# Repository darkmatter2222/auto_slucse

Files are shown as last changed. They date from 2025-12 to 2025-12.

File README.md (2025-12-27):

# Auto SLUCSE - Stepper Motor Controller

A smooth, precision stepper motor controller using **NodeMCU v2 (ESP8266)** with an **A4988 driver** and **SSD1306 OLED display**.





## ✨ Features

- **Constant-speed motion** (no ease-in/out)
- **Selectable speed: 1–8 revolutions per second (RPS)**
- **Momentary button** cycles speed 1 → 2 → 3 → … → 8 → 1 …
- **Simple OLED display** showing current RPS
- **No display updates during motion** - prevents motor jitter
- **ESP8266 watchdog-safe stepping** - periodic `yield()` during motion (no I2C)
- **12V single power supply** option (NodeMCU can run from 12V via VIN)

## 🎬 Demo

On boot, the motor runs continuously (clockwise) at **3 RPS**.

Press the button to cycle speed:
`1 → 2 → 3 → 4 → 5 → 6 → 7 → 8 → 1 → ...`

## 🔧 Hardware Required

| Component | Description |
|---|---|
| NodeMCU v2 | ESP8266-based microcontroller |
| A4988 | Stepper motor driver (or compatible) |
| NEMA 17 | Stepper motor (200 steps/rev, 1.8°) |
| SSD1306 | 128x64 OLED display (I2C, 0x3C address) |
| 12V PSU | Power supply (2A+ recommended) |

## 📌 Pin Configuration

| NodeMCU Pin | GPIO | Connected To |
|---|---|---|
| D5 | GPIO14 | A4988 STEP |
| D6 | GPIO12 | A4988 DIR |
| D1 | GPIO5 | SSD1306 SCL |
| D2 | GPIO4 | SSD1306 SDA |
| D7 | GPIO13 | Speed button (momentary to GND) |
| VIN | - | 12V Power (or 5V) |
| GND | - | Common Ground |

## 📐 Wiring

See **[WIRING.md](WIRING.md)** for complete wiring diagrams.

### Quick Reference
```
┌─────────────┐         ┌─────────────┐         ┌─────────────┐
│   12V PSU   │         │   NodeMCU   │         │    A4988    │
├─────────────┤         ├─────────────┤         ├─────────────┤
│ +12V ───────┼────┬────┼─► VIN       │         │             │
│             │    │    │             │         │             │
│             │    └────┼─────────────┼────────►│ VMOT        │
│             │         │             │         │             │
│ GND ────────┼────┬────┼─► GND       │         │             │
│             │    └────┼─────────────┼────────►│ GND         │
└─────────────┘         │             │         │             │
                        │ D5 (GPIO14) ┼────────►│ STEP        │
                        │ D6 (GPIO12) ┼────────►│ DIR         │
                        │ 3.3V ───────┼────────►│ VDD         │
                        │             │         │             │
                        │ D1 (SCL) ───┼──┐      │ RST ──┬── SLP│
                        │ D2 (SDA) ───┼──┤      │       └─► 3.3V│
                        └─────────────┘  │      └─────────────┘
                                         │
                        ┌─────────────┐  │
                        │   SSD1306   │  │
                        ├─────────────┤  │
                        │ SCL ◄───────┼──┤
                        │ SDA ◄───────┼──┘
                        │ VCC ◄─ 3.3V │
                        │ GND ◄─ GND  │
                        └─────────────┘
```

## 🚀 Build & Upload

### Prerequisites
- [PlatformIO](https://platformio.org/) (VS Code extension recommended)

### Commands
```powershell
# Build
pio run

# Upload to NodeMCU
pio run -t upload

# Monitor serial output
pio device monitor -b 115200
```

## ⚙️ Configuration

Edit `src/main.cpp` to customize:

```cpp
const int STEPS_PER_REV = 200;      // Motor steps per revolution
// Speed is selected at runtime via the button (1-8 RPS).
// Button uses INPUT_PULLUP: wire momentary switch between D7 and GND.
```

## 🔬 Technical Details

### Display Updates
The display **ONLY updates before and after motion** - never during stepping. This is critical because I2C communication during stepping causes motor jitter.

### ESP8266 Watchdog (Important)
On ESP8266, long tight stepping loops can trigger watchdog resets if the background tasks aren’t serviced. The firmware includes a lightweight periodic `yield()` during stepping.

This `yield()`:
- Helps prevent resets that can *look like* “it never reverses” (because the program restarts and re-enters the first phase)
- Does **not** touch I2C/OLED, so it’s far less disruptive than display updates

### Smoothness / Resonance
Some step rates can be audibly harsher because stepper + mechanics can resonate at certain step frequencies.
This firmware keeps step timing strictly periodic for stable torque (no intentional per-step jitter), and relies on driver tuning (current limit, decay behavior) and mechanical setup for best acoustics.

## 📁 Project Structure

```
auto_slucse/
├── src/
│   └── main.cpp          # Main application code
├── test_CFD/              # CFD experiments (STL + notebooks)
│   └── fluid_app/         # Local 3D viewer + GPU LBM prototype
├── platformio.ini        # PlatformIO configuration
├── README.md             # This file
├── WIRING.md             # Detailed wiring guide
└── .gitignore            # Git ignore rules
```

## 🌊 CFD Prototype (Local App)

There is an experimental local app in [test_CFD/fluid_app/README.md](test_CFD/fluid_app/README.md) that:
- Loads the STL in a 3D view (rotate/pivot)
- Lets you select gravity direction and click a water source point
- Runs a GPU-accelerated (PyTorch/CUDA) LBM-style simulation and plays back particle animation

## 🐛 Troubleshooting

| Problem | Solution |
|---|---|
| Motor vibrates but doesn't rotate | Check coil wiring - swap one coil pair |
| Motor doesn't move at all | Verify common ground between PSU and NodeMCU |
| Display not found | Check I2C address (usually 0x3C or 0x3D) |
| Jerky motion | Ensure display updates are between rotations |
| Motor skips steps | Increase minimum delay or reduce speed |

## 📄 License

MIT License - feel free to use and modify!

## 🙏 Acknowledgments

- Adafruit for the excellent GFX and SSD1306 libraries
- The PlatformIO team for the build system

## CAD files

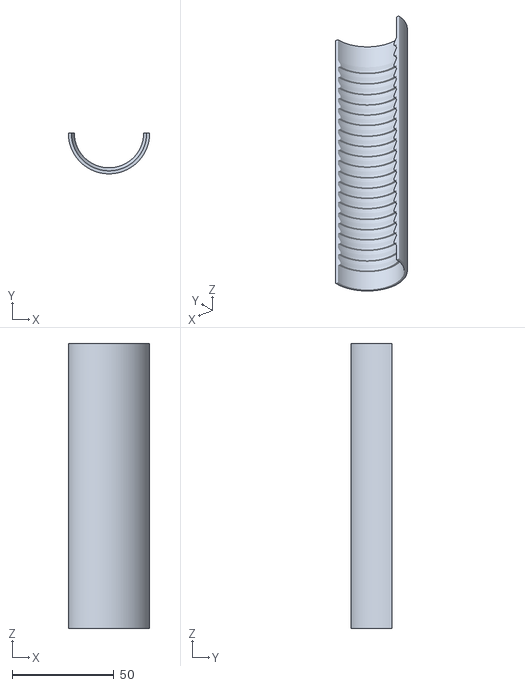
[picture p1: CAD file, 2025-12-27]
test_CFD/SmallRiffleLotsFlume.stl
40.0 x 20.0 x 140.0

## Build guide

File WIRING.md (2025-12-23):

# Wiring Guide

Complete wiring instructions for the Auto SLUCSE stepper motor controller.

## 📋 Components

| Component | Model/Specs |
|---|---|
| Microcontroller | NodeMCU v2 (ESP8266) |
| Stepper Driver | A4988 (HiLetgo or similar) |
| Stepper Motor | NEMA 17 (42HS40-005B or similar, 200 steps/rev) |
| Display | SSD1306 128x64 OLED (I2C) |
| Power Supply | 12V DC, 2A+ recommended |

---

## 🔌 Connection Tables

### NodeMCU → A4988 Stepper Driver

| NodeMCU Pin | GPIO | A4988 Pin | Notes |
|---|---|---|---|
| D5 | GPIO14 | STEP | Step pulse input |
| D6 | GPIO12 | DIR | Direction control |
| 3.3V | - | VDD | Logic power (3.3-5V) |
| GND | - | GND | Common ground |

### A4988 Internal Connections

| A4988 Pin | Connect To | Notes |
|---|---|---|
| RST | SLP | Jumper these together |
| SLP | RST + VDD | Keeps driver enabled |
| MS1 | (floating) | Full-step mode |
| MS2 | (floating) | Full-step mode |
| MS3 | (floating) | Full-step mode |

### A4988 → Motor & Power

| A4988 Pin | Connect To | Notes |
|---|---|---|
| VMOT | +12V | Motor power (8-35V) |
| GND | -12V (GND) | Motor power ground |
| 1A | Motor Coil A+ | Black wire (typically) |
| 1B | Motor Coil A- | Green wire (typically) |
| 2A | Motor Coil B+ | Red wire (typically) |
| 2B | Motor Coil B- | Blue wire (typically) |

> ⚠️ **Motor wire colors vary by manufacturer!** If motor vibrates but doesn't rotate, swap one coil pair (e.g., swap 1A and 1B).

### NodeMCU → SSD1306 Display

| NodeMCU Pin | GPIO | SSD1306 Pin | Notes |
|---|---|---|---|
| D1 | GPIO5 | SCL | I2C Clock |
| D2 | GPIO4 | SDA | I2C Data |
| 3.3V | - | VCC | Display power |
| GND | - | GND | Common ground |

---

## 🔘 Speed Button (Momentary)

The firmware supports a **momentary pushbutton** that cycles motor speed:
`1 → 2 → 3 → 4 → 5 → 1 ...` revolutions per second (RPS).

Wire it like this (no extra resistors needed):

| NodeMCU Pin | GPIO | Button Pin | Notes |
|---|---|---|---|
| D7 | GPIO13 | One side | Configured as `INPUT_PULLUP` |
| GND | - | Other side | Button shorts D7 to GND when pressed |

---

## ⚡ Power Options

### Option 1: Single 12V Supply (Recommended)

Use one 12V power supply for everything (recommended wiring):

```
┌─────────────────┐
│   12V SUPPLY    │
├─────────────────┤
│                 │
│  +12V ──────────┼──────┬──────────► A4988 VMOT
│                 │      │
│                 │      └──────────► 7805 IN
│                 │
│  GND ───────────┼──────┬──────────► A4988 GND
│                 │      │
│                 │      ├──────────► 7805 GND
│                 │      ├──────────► NodeMCU GND
│                 │      │
│                 │      └──────────► SSD1306 GND
└─────────────────┘

7805 OUT (+5V) ─────────────────────► NodeMCU VIN (5V input)

NodeMCU 3.3V ───────────────────────► A4988 VDD (logic)
NodeMCU 3.3V ───────────────────────► SSD1306 VCC
```

Notes:
- This setup avoids feeding 12V directly into the NodeMCU.
- **Common ground is mandatory:** 12V GND, 7805 GND, NodeMCU GND, and A4988 GND/VMOT GND must all be tied together.
- Add a **100–470µF (25V+) electrolytic** across **A4988 VMOT↔GND** close to the driver to reduce spikes/resets.

### Option 2: Dual Power Supplies

If you have separate 5V and 12V supplies:

```
┌─────────────────┐
│   12V SUPPLY    │
├─────────────────┤
│  +12V ──────────┼──────────────────► A4988 VMOT
│  GND ───────────┼──────┬───────────► A4988 GND
└─────────────────┘      │
                         │ (COMMON GROUND - CRITICAL!)
┌─────────────────┐      │
│    5V SUPPLY    │      │
├─────────────────┤      │
│  +5V ───────────┼──────────────────► NodeMCU VIN (or USB)
│  GND ───────────┼──────┴───────────► NodeMCU GND
└─────────────────┘
```

> ⚠️ **CRITICAL:** The grounds MUST be connected together! Without common ground, the STEP/DIR signals won't work.

---

## 📊 Complete Wiring Diagram

```
                                    ┌─────────────────────────────────────┐
                                    │            A4988 DRIVER             │
                                    │                                     │
     ┌──────────────────────────────┤ VMOT                                │
     │                              │                                     │
     │   ┌──────────────────────────┤ GND                            1A ├───► Motor Coil A+
     │   │                          │                                     │
     │   │   ┌──────────────────────┤ VDD                            1B ├───► Motor Coil A-
     │   │   │                      │                                     │
     │   │   │                      │ RST ◄────┐                     2A ├───► Motor Coil B+
     │   │   │                      │          │ (jumper)                 │
     │   │   │                      │ SLP ◄────┴──► 3.3V             2B ├───► Motor Coil B-
     │   │   │                      │                                     │
     │   │   │   ┌──────────────────┤ STEP                               │
     │   │   │   │                  │                                     │
     │   │   │   │   ┌──────────────┤ DIR                                │
     │   │   │   │   │              │                                     │
     │   │   │   │   │              │ MS1  (floating = full step)        │
     │   │   │   │   │              │ MS2  (floating = full step)        │
     │   │   │   │   │              │ MS3  (floating = full step)        │
     │   │   │   │   │              │                                     │
     │   │   │   │   │              │ EN   (floating = enabled)          │
     │   │   │   │   │              └─────────────────────────────────────┘
     │   │   │   │   │
     │   │   │   │   │              ┌─────────────────────────────────────┐
     │   │   │   │   │              │            NodeMCU v2               │
     │   │   │   │   │              │                                     │
     │   │   │   │   └──────────────┤ D6 (GPIO12)                        │
     │   │   │   │                  │                                     │
     │   │   │   └──────────────────┤ D5 (GPIO14)                        │
     │   │   │                      │                                     │
     │   │   └──────────────────────┤ 3.3V ──────────┬───────────────────┼───► SSD1306 VCC
     │   │                          │                │                   │
     │   └──────────────────────────┤ GND ───────────┼───────────────────┼───► SSD1306 GND
     │                              │                │                   │
     └──────────────────────────────┤ VIN            │                   │
                                    │                │                   │
                                    │ D1 (GPIO5) ────┼───────────────────┼───► SSD1306 SCL
                                    │                │                   │
                                    │ D2 (GPIO4) ────┼───────────────────┼───► SSD1306 SDA
                                    │                │                   │
                                    └────────────────┼───────────────────┘
                                                     │
                                    ┌─────────────────────────────────────┐
                                    │         7805 REGULATOR MODULE       │
                                    │                                     │
                                    │ IN  ◄────────── +12V                │
                                    │ GND ◄────────── 12V GND (common)    │
                                    │ OUT ───────────► +5V to NodeMCU VIN │
                                    └─────────────────────────────────────┘

┌─────────────────┐
│   12V SUPPLY    │
├─────────────────┤
│  +12V ──────────┼──► A4988 VMOT and 7805 IN
│  GND ───────────┼──► all GND points (common ground)
└─────────────────┘

Add near A4988: 100–470uF electrolytic across VMOT↔GND (25V+)
```

---

## 🔍 Motor Coil Identification

### Finding Coil Pairs

Use a multimeter in continuity/resistance mode:
1. Touch two wires together
2. If you get ~5Ω (low resistance), they're a coil pair
3. The other two wires are the second coil pair

### Typical NEMA 17 Wire Colors

| Coil | Wire 1 | Wire 2 |
|---|---|---|
| A | Black | Green |
| B | Red | Blue |

> **Note:** Colors vary! Always verify with a multimeter.

### If Motor Vibrates But Doesn't Rotate

The coil pairs are probably wired incorrectly. Try:
1. Swap wires on 1A and 1B, OR
2. Swap wires on 2A and 2B

---

## ✅ Verification Checklist

Before powering on:

- [ ] 12V connected to VMOT (not VDD!)
- [ ] NodeMCU powered from +5V into VIN (e.g., via 7805/buck), not directly from 12V
- [ ] VDD connected to 3.3V (not 12V!)
- [ ] All GND points connected together
- [ ] VMOT electrolytic capacitor installed near the A4988 (100–470µF, 25V+)
- [ ] RST and SLP jumpered together
- [ ] RST/SLP jumper connected to 3.3V
- [ ] Motor coils verified with multimeter
- [ ] Display I2C connections (D1=SCL, D2=SDA)

---

## 🐛 Troubleshooting

| Symptom | Likely Cause | Solution |
|---|---|---|
| Motor doesn't move | No common ground | Connect all GNDs together |
| Motor vibrates chaotically | Wrong coil wiring | Swap one coil pair |
| Motor very weak | Low VMOT voltage | Ensure 12V at VMOT |
| Motor gets very hot | Current limit too high | Adjust A4988 potentiometer |
| Display blank | Wrong I2C address | Try 0x3D instead of 0x3C |
| Display shows garbage | SDA/SCL swapped | Swap D1 and D2 connections |
| A4988 gets hot | No heatsink | Add heatsink to A4988 |

---

## 📏 A4988 Current Limiting

The A4988 has a small potentiometer for current limiting. To set it:

1. Measure voltage at the potentiometer center (Vref)
2. Calculate: `I_max = Vref / (8 × Rs)` where Rs is the sense resistor (usually 0.1Ω)
3. For Rs = 0.1Ω: `I_max = Vref × 1.25`

For NEMA 17 motors, Vref of ~0.4-0.8V is typical (0.5-1A per phase).

> ⚠️ Start LOW and increase gradually. Too much current = overheating!

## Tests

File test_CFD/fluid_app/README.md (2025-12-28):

# Fluid App (STL + Gravity Flow)

This is a local app that:
- Loads the STL in a 3D view (rotate/pivot in space)
- Lets you pick a gravity direction
- Lets you click the STL to pick a water source location
- Lets you set flow rate (GPH) and a quality level
- Runs a GPU-accelerated LBM-style solver (PyTorch/CUDA) and returns an animated particle playback

## 1) Start the backend (Python)

```powershell
Set-Location "C:\Users\ryans\source\repos\auto_slucse\test_CFD\fluid_app\backend"
python -m pip install -r requirements.txt

# Install a CUDA build of torch that matches your system:
# https://pytorch.org/get-started/locally/

./run_server.ps1
```

Backend: `http://127.0.0.1:8010`

## 2) Start the frontend (React)

```powershell
Set-Location "C:\Users\ryans\source\repos\auto_slucse\test_CFD\fluid_app\frontend"
npm install
npm run dev
```

Frontend: `http://localhost:5173`

## Use

- Rotate the STL with the mouse (OrbitControls).
- If you translate/rotate the STL with TransformControls, picking and particle playback stay aligned with the moved model (the frontend converts world-space clicks/gravity into STL-local coordinates before sending the request).
- Click the STL to set the source point.
- Set **Gravity direction**, **Flow rate**, and **Rendering intensity**.
- Click **Build to go**.

Notes:
- The backend currently treats the STL as a *solid* and simulates flow in the surrounding box (same basic assumption as the existing notebook). For internal-channel flow, the geometry needs a fluid-volume mesh or an STL that represents the negative space.

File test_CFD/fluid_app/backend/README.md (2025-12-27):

# Fluid App Backend

FastAPI service that:
- Serves the STL
- Runs a GPU-accelerated (PyTorch) D3Q19 LBM solver
- Generates particle-frame animation data (`.npz`)

## Run

From this folder:

```powershell
python -m pip install -r requirements.txt
# Install a CUDA build of torch that matches your system:
# https://pytorch.org/get-started/locally/

./run_server.ps1
```

API base: `http://127.0.0.1:8010`

- `GET /api/stl`
- `POST /api/simulate`
- `GET /api/run/{runId}/status`
- `GET /api/run/{runId}/result`

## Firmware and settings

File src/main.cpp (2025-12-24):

#include <Arduino.h>
#include <Wire.h>
#include <Adafruit_GFX.h>
#include <Adafruit_SSD1306.h>

// Display setup - I2C on D1(SCL) and D2(SDA)
#define SCREEN_WIDTH 128
#define SCREEN_HEIGHT 64
#define OLED_RESET -1
Adafruit_SSD1306 display(SCREEN_WIDTH, SCREEN_HEIGHT, &Wire, OLED_RESET);

const int DIR = 12;   // D6
const int STEP = 14;  // D5
const int SPEED_BTN = 13;  // D7 - momentary button to GND (INPUT_PULLUP)
const int STEPS_PER_REV = 200;
static constexpr uint8_t RPS_MIN = 1;
static constexpr uint8_t RPS_MAX = 8;
static constexpr uint16_t STEP_PULSE_US = 10;
static constexpr uint16_t BUTTON_DEBOUNCE_MS = 35;

uint8_t currentRps = 3;  // Boot at 3 revolutions per second
bool uiUpdatePending = true;

struct DebouncedButton {
  bool lastReading = false;
  bool stableState = false;
  uint32_t lastChangeMs = 0;
};

DebouncedButton speedButton;

void showRps(uint8_t rps) {
  display.clearDisplay();
  display.setTextSize(1);
  display.setTextColor(SSD1306_WHITE);
  display.setCursor(0, 0);
  display.println("STEPPER CONTROL");

  display.setTextSize(2);
  display.setCursor(0, 18);
  display.println("SPEED");

  display.setTextSize(2);
  display.setCursor(0, 42);
  display.print(rps);
  display.println(" RPS");

  display.display();
}

bool isSpeedButtonPressedEvent() {
  const uint32_t nowMs = millis();
  const bool readingPressed = (digitalRead(SPEED_BTN) == LOW);

  if (readingPressed != speedButton.lastReading) {
    speedButton.lastReading = readingPressed;
    speedButton.lastChangeMs = nowMs;
  }

  if ((nowMs - speedButton.lastChangeMs) < BUTTON_DEBOUNCE_MS) {
    return false;
  }

  if (speedButton.stableState != readingPressed) {
    speedButton.stableState = readingPressed;
    if (speedButton.stableState) {
      return true;  // pressed (stable) edge
    }
  }

  return false;
}

uint32_t stepIntervalUsForRps(uint8_t rps) {
  if (rps < RPS_MIN) rps = RPS_MIN;
  if (rps > RPS_MAX) rps = RPS_MAX;

  const uint32_t stepsPerSecond = (uint32_t)rps * (uint32_t)STEPS_PER_REV;
  if (stepsPerSecond == 0) {
    return 1000000UL;
  }

  // Keep timing strictly periodic (stable torque) to avoid “pulsating” behavior.
  const uint32_t intervalUs = 1000000UL / stepsPerSecond;
  return (intervalUs < (uint32_t)STEP_PULSE_US) ? (uint32_t)STEP_PULSE_US : intervalUs;
}

void setup() {
  Serial.begin(115200);
  pinMode(STEP, OUTPUT);
  pinMode(DIR, OUTPUT);
  pinMode(SPEED_BTN, INPUT_PULLUP);
  
  // Initialize I2C for display
  Wire.begin();
  
  // Initialize display
  if (!display.begin(SSD1306_SWITCHCAPVCC, 0x3C)) {
    Serial.println("SSD1306 allocation failed");
  }

  // Set direction once at startup (continuous clockwise motion).
  // ⚠️ CRITICAL: Do not change this expression.
  const bool clockwise = true;
  digitalWrite(DIR, clockwise ? HIGH : LOW);
  delay(50);  // Direction settle

  showRps(currentRps);
  delay(500);
}

void loop() {
  if (isSpeedButtonPressedEvent()) {
    currentRps = (currentRps >= RPS_MAX) ? RPS_MIN : (uint8_t)(currentRps + 1);
    uiUpdatePending = true;
    Serial.printf("Speed changed: %u RPS\n", currentRps);
  }

  // Only update OLED when NOT actively stepping.
  if (uiUpdatePending) {
    showRps(currentRps);
    uiUpdatePending = false;
  }

  const uint32_t stepIntervalUs = stepIntervalUsForRps(currentRps);
  const uint32_t lowDelayUs = (stepIntervalUs > (uint32_t)STEP_PULSE_US)
                                ? (stepIntervalUs - (uint32_t)STEP_PULSE_US)
                                : 0;

  digitalWrite(STEP, HIGH);
  delayMicroseconds(STEP_PULSE_US);
  digitalWrite(STEP, LOW);
  if (lowDelayUs > 0) {
    delayMicroseconds(lowDelayUs);
  }

  // Avoid periodic long pauses (audible pulsation): feed WDT without yielding.
  ESP.wdtFeed();
}

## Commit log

2025-12-14 feat: Ultra-smooth stepper motor controller with OLED display
    - NodeMCU v2 (ESP8266) + A4988 stepper driver + SSD1306 OLED
    - Sine-based ease-in-out acceleration for smoothest motion
    - 5 rotations per direction, ~2 seconds total each way
    - Beautiful progress bar display with rotation counter
    - Pre-computed 1000-step delay array for jitter-free operation
    - Display updates only between rotations to prevent timing issues
    - Comprehensive README and WIRING documentation with ASCII diagrams
    - Single 12V power supply support (NodeMCU via VIN)
    [main.cpp]
2025-12-14 feat: 6 rotations with symmetric steep easing
    - Increased from 5 to 6 rotations per direction
    - Symmetric quadratic easing: quick ramp-up AND quick ramp-down
    - Speed floor at 30% prevents vibration at motion start/end
    - Peak speed maintained at 1500us (unchanged)
    - Added agents.md for AI agent context
    - Updated README.md with new specs
    [main.cpp]
2025-12-14 fix: restore bidirectional motion - increased pulse width to 50us
    - Pulse width was 10us, now 50us (matches working sample code)
    - Direction settle time increased to 100ms
    - Added delays after display updates to ensure completion
    - Updated agents.md with correct timing requirements
    [main.cpp]
2025-12-14 feat: 6 rotations with smooth motion - no mid-motion display updates
    CRITICAL CHANGES:
    - 6 rotations per direction (was 5)
    - Display updates ONLY before/after motion - NEVER during stepping
    - Removed progress bar to eliminate jitter source
    - Direction logic unchanged: digitalWrite(DIR, clockwise ? HIGH : LOW)
    This fixes motor jitter caused by I2C display updates during stepping.
    agents.md updated with:
    - CRITICAL warning about direction logic - DO NOT CHANGE
    - CRITICAL warning about display timing - causes jitter
    - Updated timing specs and troubleshooting guide
    [main.cpp]
2025-12-16 Update 12V+7805 wiring diagram
2025-12-23 Switch to continuous 1-5 RPS with button
2025-12-24 Revert step dither; stabilize timing
    [main.cpp]
2025-12-27 Add CFD fluid_app prototype
    [SmallRiffleLotsFlume.stl]
2025-12-28 Fix STL transform alignment and controls
